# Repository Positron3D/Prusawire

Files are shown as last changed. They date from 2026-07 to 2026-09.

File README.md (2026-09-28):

# Prusawire 2026.R1

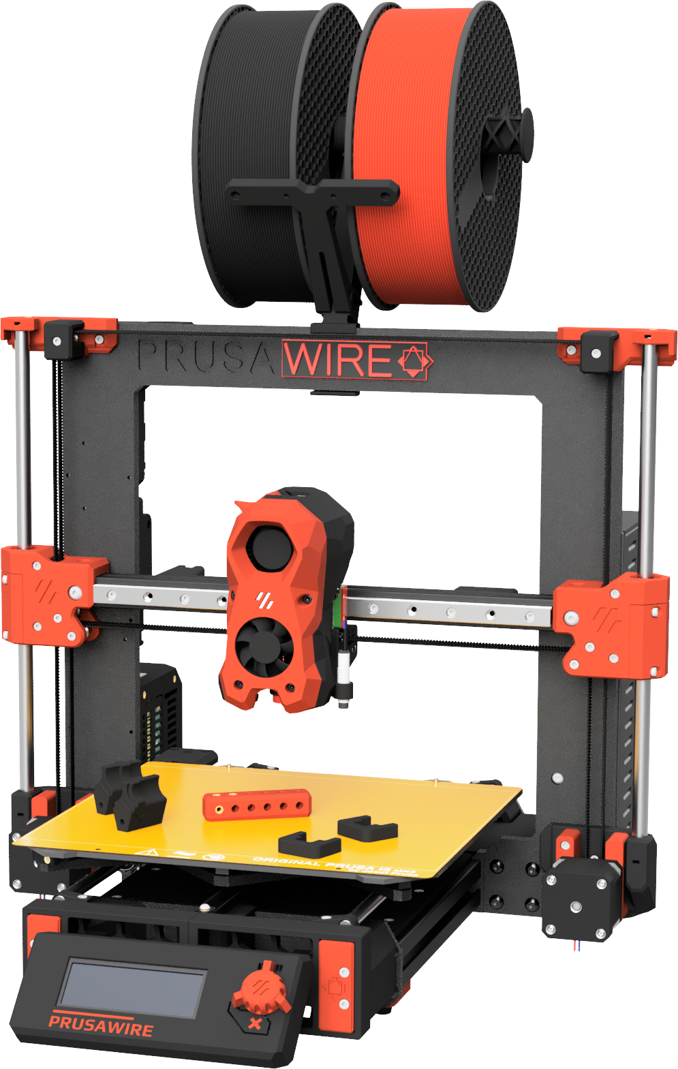
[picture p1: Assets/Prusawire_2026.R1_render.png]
Prusawire 2026.R1 Render


A Prusa MK3/MK4 to Voron Switchwire Conversion. Originally from Positron 3D's 2025 April Fools, transformed into a mature and fun 3D printer!

Build Volume: 250mm (X) by 210mm (Y) by 185mm (Z).

## Current Release

2026.R1 was released on 2026-07-24.

[Article: Prusawire R1 - Designed With Leftovers](https://www.printables.com/article/prusawire-r1-designed-with-leftovers-VNGb2GZ).

View the [changelog](CHANGELOG.md) for a for detailed listing of project evolution.

Be sure to grab the latest STLs and documentation from the GitHub Repository or use the _NEW_ [Prusawire Configurator](https://configurator.positron3d.com) to configure your Prusawire, visualize it, and download the STLs you need for your build!

## Upgrading from Beta 1
- Everything to do with XZ Axis has changed and is not compatible with R1.
- Everything to do with Y Axis has changed and is not compatible with R1.
- Electronics adjacent components (Mainboard, RPi Mount, Wago, Toolhead Board, etc), Door Idler components, Gantry Bumper, LCD Cover, and Front Panel/deck cover can be re-used.
- Existing belts can be re-used (although, depending how the belts were trimmed, it's possible you may need to replace them for being too short)

## Manual & Documentation

[Assembly Manual](Manuals/Prusawire_2026.R1_Assembly_Manual.pdf).

[Prusawire Documentation and FAQ Site](https://prusawire.positron3d.com).

The [Official Positron3D CAD Viewer](https://cad.positron3d.com?model=Prusawire_2026.R1) can be very helpful in building Prusawire.

Be sure to post your _Make_ on the [Prusawire Printables page](https://www.printables.com/model/1788294-prusawire-2026r1)!

## Bill of Materials

[Prusawire 2026.R1 Bill of Materials](https://docs.google.com/spreadsheets/d/16whAEq4oKpdtc77cCxrXZkcxw_G3URlF5wZYUE42vhc/)

Prusawire will require ~1060g of primary color filament and ~225g of accent color filament.  Accessory and component choices may affect these estimates slightly.

## Who This Printer is For

- You have an old MK3, MK3S, or MK3S+, and you want to teach an old dog new tricks and are on a budget
- You upgraded from MK4S to a Core ONE, and have a leftover frame. You are okay spending money on building a new printer with that hardware.
- You have a MK4 or MK4S that you want to Klipper-ize and experiment with!

Additionally, the following says this printer is for you: 

- You want to take your first steps into RepRap beyond Prusa, and Voron is an exciting route.
- You respect the Frankenstein-y nature of this April Fools joke printer

## Want to Support the Project?

First of all, thank you!

- Support Positron3D to fund future endeavors: 
   - [Donate to Positron3D](https://www.paypal.com/donate/?hosted_button_id=YGPRVTSHN4FQG)
   - [Positron3D Merch](https://nomadsgalaxy-shop.fourthwall.com/)

## Serial Numbers

We are accepting serial number requests on the [Positron 3D Discord](https://discord.gg/positron). Please submit your request to the #prusawire-serial-request channel over there. 

*Important Note:* Prusawire is _not_ a Voron Switchwire.  Please do not ask for help in the Voron Discord; instead utilize the #prusawire-discussions and #prusawire-questions channels on the Positron 3D Discord.

## Klipper Configuration Files

The most up–to–date Klipper configuration files for setting up or updating the Prusawire are in our [config repository](https://github.com/Positron3D/prusawire-klipper-config).

## Upgrading the Einsy Rambo to Klipper - Read this

Installing Klipper on the Einsy Rambo board is possible, with extra steps. Follow the guide [published by the awesome folks at MyRigs3D](https://myrigs3d.com/blogs/infos/revive-your-prusa-mk3s-with-klipper-1-5-flash-bootloader)! We recommend Method 2.

**Note:** Some users have reported problems using `avrdude` with the latest Raspberry Pi OS version (bookworm). If you experience error messages from avrdude complaining about gpio ports being busy, please try using the bullseye version of Raspberry Pi OS instead, available as "Raspberry Pi OS (Legacy)" in Raspberry Pi Imager.

## Credits 

Thank you to all the awesome people and companies that have made this possible.
- Positron 3D Team
- Nomads Galaxy, initial idea
- Ella Fox, the architect of Prusawire Beta 1
- Prusa Research - Prusa i3
- Voron Design - Switchwire
- Jason @ LDO Motors - Part sponsorship
- Levendigs & KB-3D - Part sponsorship
- Siraya Tech Filaments
- The many early access and beta testers

We hope you enjoy this build as much as we enjoyed making it.

The Prusawire Team:
@Safe // @erikbuild // @TheNexusAvenger

## Extra Credits for Existing Printed Parts

See the collection for the most up to date! To name them:

- Printable M3 T-Nuts for 3030 Extrusion, by Kapplion
- Stealthburner umbilical strain relief, by nagelwerkstatt

## Team

Prusawire is currently maintained by the Positron 3D Team.

- Design Lead: @Safe
- Documentation Lead: @erikbuild
- Software Lead: @TheNexusAvenger

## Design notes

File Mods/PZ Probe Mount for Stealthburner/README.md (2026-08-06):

A PZ Probe mount for the Prusawire. Use two M2 self-threading screws up to about 10mm in length to mount it. You may lose some Z distance with this mod as it may interfere with the belt path at the top.

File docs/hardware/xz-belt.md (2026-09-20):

---
layout: default
title: XZ Belt Installation and Tensioning
parent: Hardware Overview
nav_order: 2
---

# XZ Belt Installation and Tensioning
{: .no_toc}

<details open markdown="block">
  <summary>
    Table of contents
  </summary>
  {: .text-delta }
- TOC
{:toc}
</details>

**Compatibility:** *Prusawire 2026.R1*

## Overview
The X and Z belts must be installed and tensioned properly to ensure smooth and accurate gantry motion.

**Important notes:**
- Extra belt length has been specified in the BOM; it is expected to have some leftover belt afterwards.
- Match your belt lengths before assembling the printer!
- When inserting the belt clips, there should be an equal number of teeth sticking out of the ends.
- **DO NOT cut your belts** until you are 1000% certain you have done it correctly.  It's okay to leave a little extra length hanging out the back of the toolhead carriage until final assembly and validation.

## Prerequisites
- Complete the Gantry Deracking procedure.
- Remove the **toolhead** from the **carriage mount** (if currently installed).
	1. For Stealthburner, see the Stealthburner assembly manual for instructions.
- (Optional, but highly recommended) Print and assemble the GT2 Belt Runner to easily and perfectly match your belt lengths: [Belt Runner - GT2 Belt Length Matcher \| Printables.com](https://www.printables.com/model/1192440-belt-runner-gt2-belt-length-matcher)

## Instructions 
### Belt Installation
1. Measure out 1600mm of GT2 belt for the X axis.  Double-check your measurement, then cut this length.  Set aside for now.
	- *Tip: Mark some tape on your desk with 100mm increments using a tape measure or calipers.*

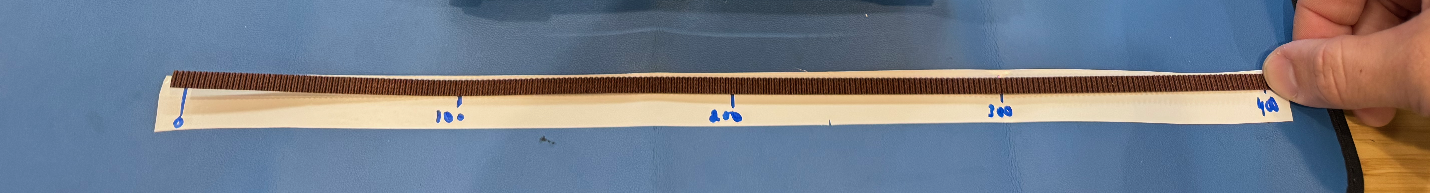
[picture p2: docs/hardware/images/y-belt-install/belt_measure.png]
	

2. Measure out another ~1600mm length of GT2 belt for the Z axis.  **Do not cut it yet!**
3. Match the belt lengths (*note: if not using the GT2 Belt Runner, carefully match the belt lengths by hand!*)
	1. Align the starting teeth of the of the X belt and Z belt.  
	2. Feed into the GT2 Belt Runner (see above).  
	3. Use belt runner to find the exact same length of Z belt as X belt.  Note one belt will be exactly one tooth offset from the other.  
	4. Once you are sure the belts are the same length, cut the **Z belt** to match the **X belt**.

	
	
4. Using tape or a zip tie, raise the gantry about 75% of the way towards the top of the frame.

	
	
5. Remove the 4x **M3x14 SHCS** securing the **x carriage assembly** to the linear rail.  Remove the assembly.
	
	

6. Remove the 3x **M3x40 SHCS** from the left side of the **x-carriage assembly** to separate the left side from the right side.
	
	

7. Gather all the needed parts:
	- 2x **1600mm Gates GT2 Belt**
	- 2x **M3x40 SHCS**
	- 2x **\[a]_belt_tensioner_clip**
	- 2x **\[a]_belt_clip**
	- 2x **belt_clip**
	- 4x **M3x14 SHCS**
	- 1x **x-carriage - left side**
	- 1x **x-carriage - right side**

	
    
8. Take the **x-carriage - right side** and install it back onto the **x-carriage mount** (on the rail) with 2x **M3x14 SHCS**.
9. Take the first **\[a]_belt_tensioner_clip**.  Feed a small amount of one of the belts (belt teeth facing up) through the slot on the side with the heat insert.  Pass just enough belt through so 3 teeth are visible from the opposite side.  Insert a **belt_clip** under to secure.
	- *Tip: You can press the retaining clip against a flat surface to help force the retaining clip into the tensioner clip.*
    
	
	

10. Repeat this process for the other clip and belt.  It is critical for both clips to have the same number of exposed belt teeth showing.
11. Pass the long end of each belt (teeth facing up) through the two slots from the inside to the outside of the mounted **x-carriage - right side**.
	- *NOTE: The **\[a]_belt_tensioner_clip** with the single dot goes towards the rear of the printer.  The clip with the two dots goes towards the front of the printer.

	
	

12. **Z Belt**: Route the belt through the belt path (see diagram; belt path noted in GREEN):
	1. Right towards the **XZ Block - Right**.
	2. Around the bearing stack and down towards the **Z Motor**.
	3. Back up around the **Z Motor Pulley** through the **XZ Block - Right** towards the **Idler Block - Right**.
	4. Around the bearing stack and left towards **Idler Block - Left**.
	5. Around the bearing stack and down towards **XZ Block - Left**.
	6. Around the bearing stack and right towards the **X-carriage**.
	7. *Tip: Make sure the belt isn't twisted at any point!*
	8. *Tip: Check the Z Motor Pulley alignment with the belt.  Adjust with the set screws on the pulley if needed to ensure good belt alignment that doesn't rub on the motor mounts.*

	
	

13. **X Belt**: Route the belt through the belt path (see diagram; belt path noted in YELLOW):
	1. Right towards the **XZ Block - Right**.
	2. Around the bearing stack and up towards **Idler Block - Right**.
	3. Around the bearing stack and left towards **Idler Block - Left**.
	4. Around the bearing stack and down through **XZ Block - Left** towards **X Motor**.
	5. Back up around the **X Motor Pulley** towards **XZ Block - Left**.
	6. Around the bearing block and right towards the **x-carriage**.
	7. *Tip: Make sure the belt isn't twisted at any point!*
	8. *Tip: Check the X Motor Pulley alignment with the belt.  Adjust with the set screws on the pulley if needed to ensure good belt alignment that doesn't rub on the motor mounts.*

	

14. Pass the two belts through the outside of the **x-carriage - left side**.  
	
	

15. Rejoin the **x-carriage - left side** to the mounted carriage with the 3x **M3x40 SHCS**.  Direct the excess belt length down for now.

	

16. Pull the excess belts evenly to remove the slack from the belt system.  Carefully line up the ends of the belts to ensure they are the same length and the ends match up evenly.
17. Insert both **\[a]_belt_clips** to secure the belts to the left side of the carriage.

	

18. Confirm once again the ends of the belts are perfectly aligned.  If they have shifted, remove the clips and re-adjust.
19. Unmount the **x-carriage assembly** from the linear rail one last time by removing the 2x **M3x14 SHCS** from the front.
20. Carefully rotate the assembly towards you to view the belts inside.

	

21. Leaving 3 to 4 teeth exposed on the left side of the assembly, carefully cut the belts.

	

22. Re-mount the assembly back onto the linear rail carriage with all 4x **M3x14 SHCS**.
23. Install the 2x **M3 x 40 SHCS** into the left side of the **x-carriage assembly** and screw into the **\[a]_belt_tensioner_clips** until just seated.
	
	

24. You are finished and ready to tension the XZ Belts!

	

### Belt Tensioning
To properly tension the X and Z belts:
1. Begin turning the two **M3x40 SHCS tensioning screws** in the **x-carriage assembly**.
	- Turn clockwise to increase tension.
	- Turn counterclockwise to decrease tension.
2. Once slack is removed, and prior to final tension:
	- **TRIPLE CHECK YOUR BELTS to make sure they are riding correctly on the bearings and pulleys.  If they aren't, loosen and correct.**
3. If the tensioning screw bottoms out you can either:
	- Replace the M3x40 SHCS with a fully threaded version
	- Try tensioning both belts a few more groove notches on the left side of the **x-carriage assembly** and re-installing the **\[a]_belt_tensioner_clips** to secure.

4. Visually inspect your X carriage belt tensioner. If your belts are not stretched, you should see that the two tensioner blocks are almost in line with one another. 
	
	
    
5. Come to the front of the printer and inspect the right side of your X carriage. Your belt teeth should align with one another. If they do not, make minor adjustments to the tensioner screws until they do.
	
	

6. Follow up with tuning your belt tension with one of the final tensioning options below.

**Final Tensioning Options:**
- **PF Makes Belt Tensioning Meter:** [3D-Printer/GT2 Belt Tension Meter at main · Diyshift/3D-Printer · GitHub](https://github.com/Diyshift/3D-Printer/tree/main/GT2%20Belt%20Tension%20Meter)
	- Switchwire "Z" Spec - 1.8 to 2.2 (1.9 to 2.3 for EPDM high-temp belt)
- **Prusa Mobile App:** 
	- [Prusa on the Apple App Store](https://apps.apple.com/us/app/prusa/id6477531937)
	- [Prusa - Apps on Google Play](https://play.google.com/store/apps/details?id=com.prusa3d.connect&hl=en-US&pli=1)
	- Tuner Mode for *MK3S --> X-Axis*
		- Carriage all the way to the right
- **Prusa Website Tuner:** [Prusa Belt tuner](https://belt.connect.prusa3d.com/)
	- *MK3S --> X-Axis*
		- Carriage all the way to the right
- **Gates Carbon Drive Mobile App**
	- [Carbon Drive Belt Tension Tool on the Apple App Store](https://apps.apple.com/app/bicycle-belt-tension-meter/id438346486)
	- [Carbon Drive - Apps on Google Play](https://play.google.com/store/apps/details?id=com.gates.carbondrivecalculator&hl=en)
	- 85 Hz

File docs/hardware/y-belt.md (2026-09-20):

---
layout: default
title: Y Belt Installation and Tensioning
parent: Hardware Overview
nav_order: 2
---

# Y Belt Installation and Tensioning
{: .no_toc}

<details open markdown="block">
  <summary>
    Table of contents
  </summary>
  {: .text-delta }
- TOC
{:toc}
</details>

**Compatibility:** *Prusawire 2026.R1*

## Overview
The Y belt must be installed and tensioned properly to ensure smooth and accurate bed motion.

**Important notes:**
- Extra belt length has been specified in the BOM; it is expected to have some leftover belt afterwards.
- Match your belt lengths before assembling the printer!
- When inserting the belt clips, there should be an equal number of teeth sticking out of the ends.
- **DO NOT cut your belts** until you are 1000% certain you have done it correctly.  It's okay to leave a little extra length hanging out the back of the toolhead carriage until final assembly and validation.

## Prerequisites
- You will likely find this easiest without the MK52 Heat Bed installed!

## Instructions 
### Belt Installation
1. Measure out 1000mm of GT2 belt for the Y axis.  Double-check your measurement, then cut this length.  Set aside for now.
	- *Tip: Mark some tape on your desk with 100mm increments using a tape measure or calipers.*

	

2. Gather all the needed parts:
	- 1x **1000mm Gates GT2 Belt**

3. Slightly loosen the M3x10 BHCS securing **y_belt_tensioner** to the Y Carriage.  Loosen the M3x20 SHCS tensioning screw almost all the way so the **y_belt_tensioner_front** can be pulled apart as much as possible (while the M3x20 is still engaged with the square nut).  This is the position of LEAST belt tension.

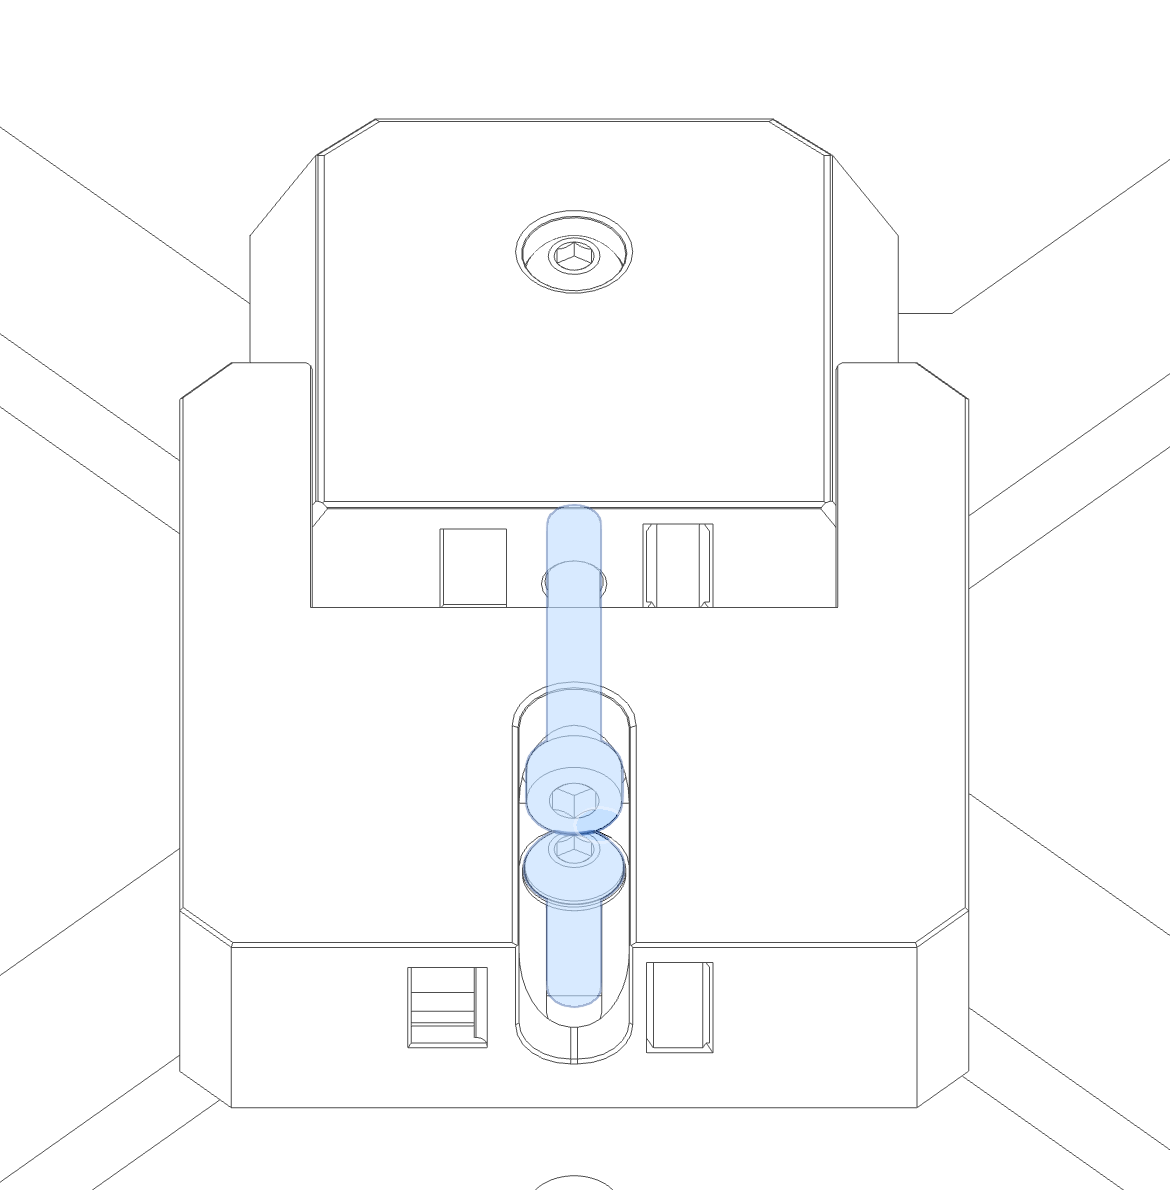
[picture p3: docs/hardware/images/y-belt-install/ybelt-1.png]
	
 
4. Insert one end of the belt into **y_belt_tensioner** as shown.  Ensure at least 6 teeth of the belt are in contact with the ridges on the tensioner.

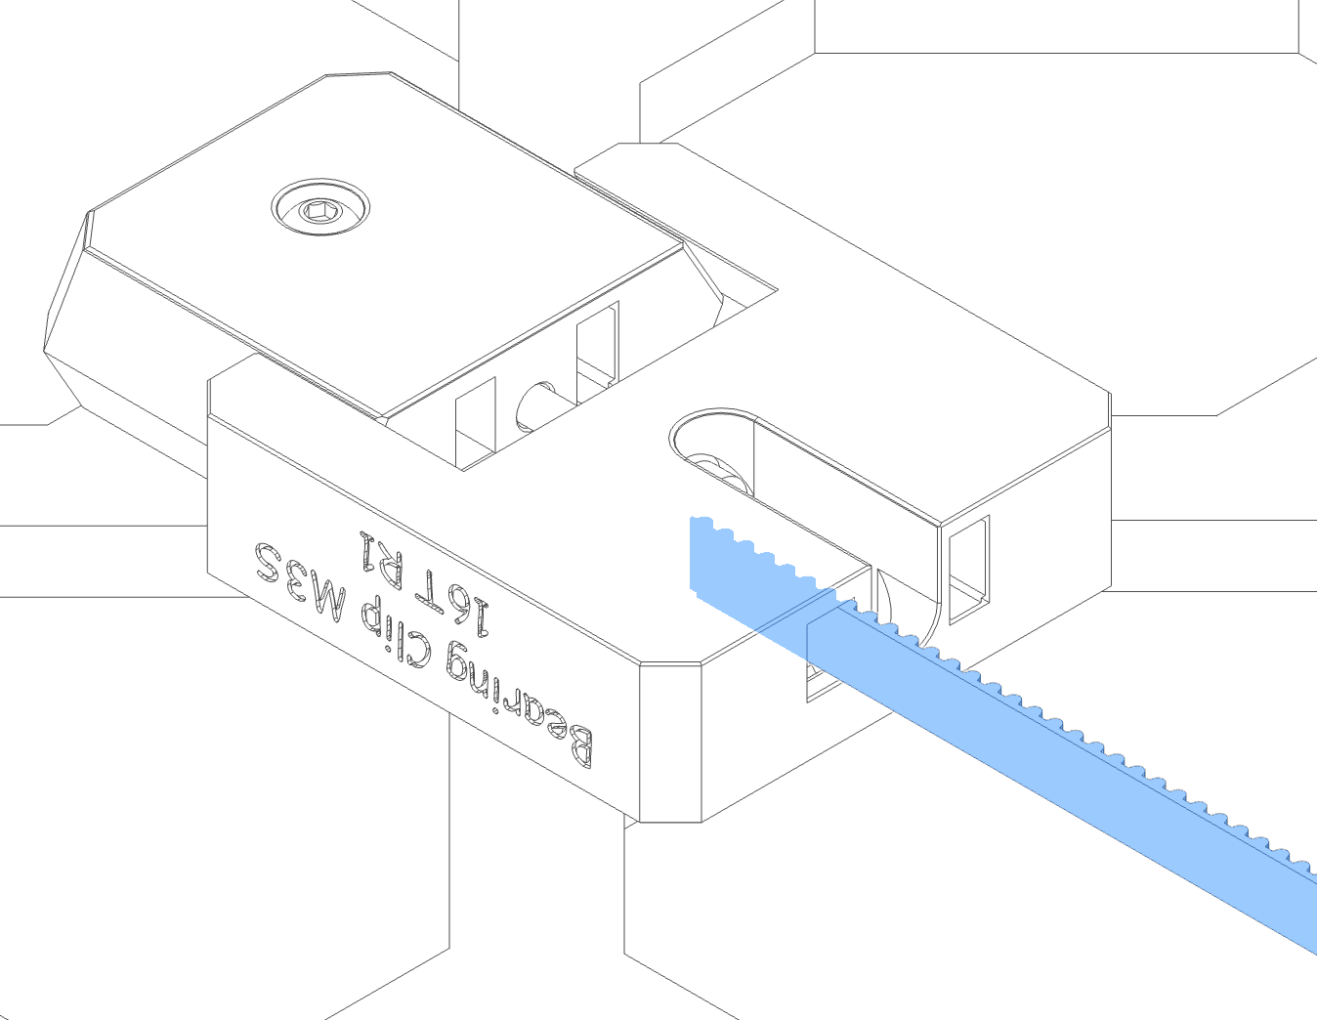
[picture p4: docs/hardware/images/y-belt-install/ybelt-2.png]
	

5. Insert **[a]_belt_clip** to secure the belt.

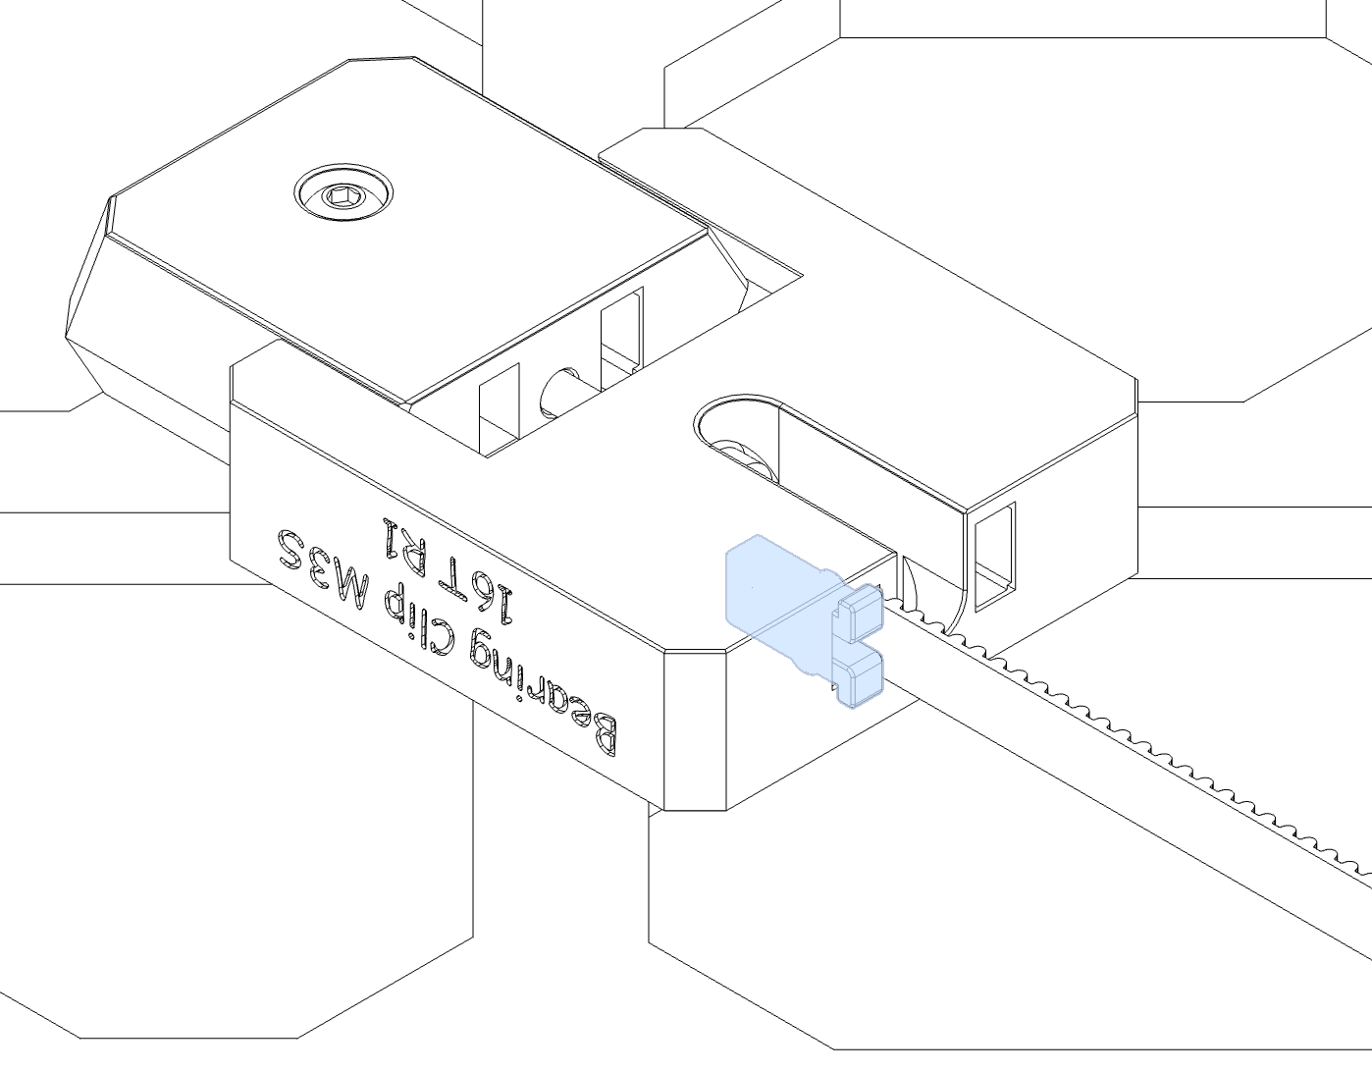
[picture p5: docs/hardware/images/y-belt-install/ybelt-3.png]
	

6. Route the belt towards the front, around the front idler bearing stack, back into and through both halves of **y_belt_tensioner** towards the back of the printer.

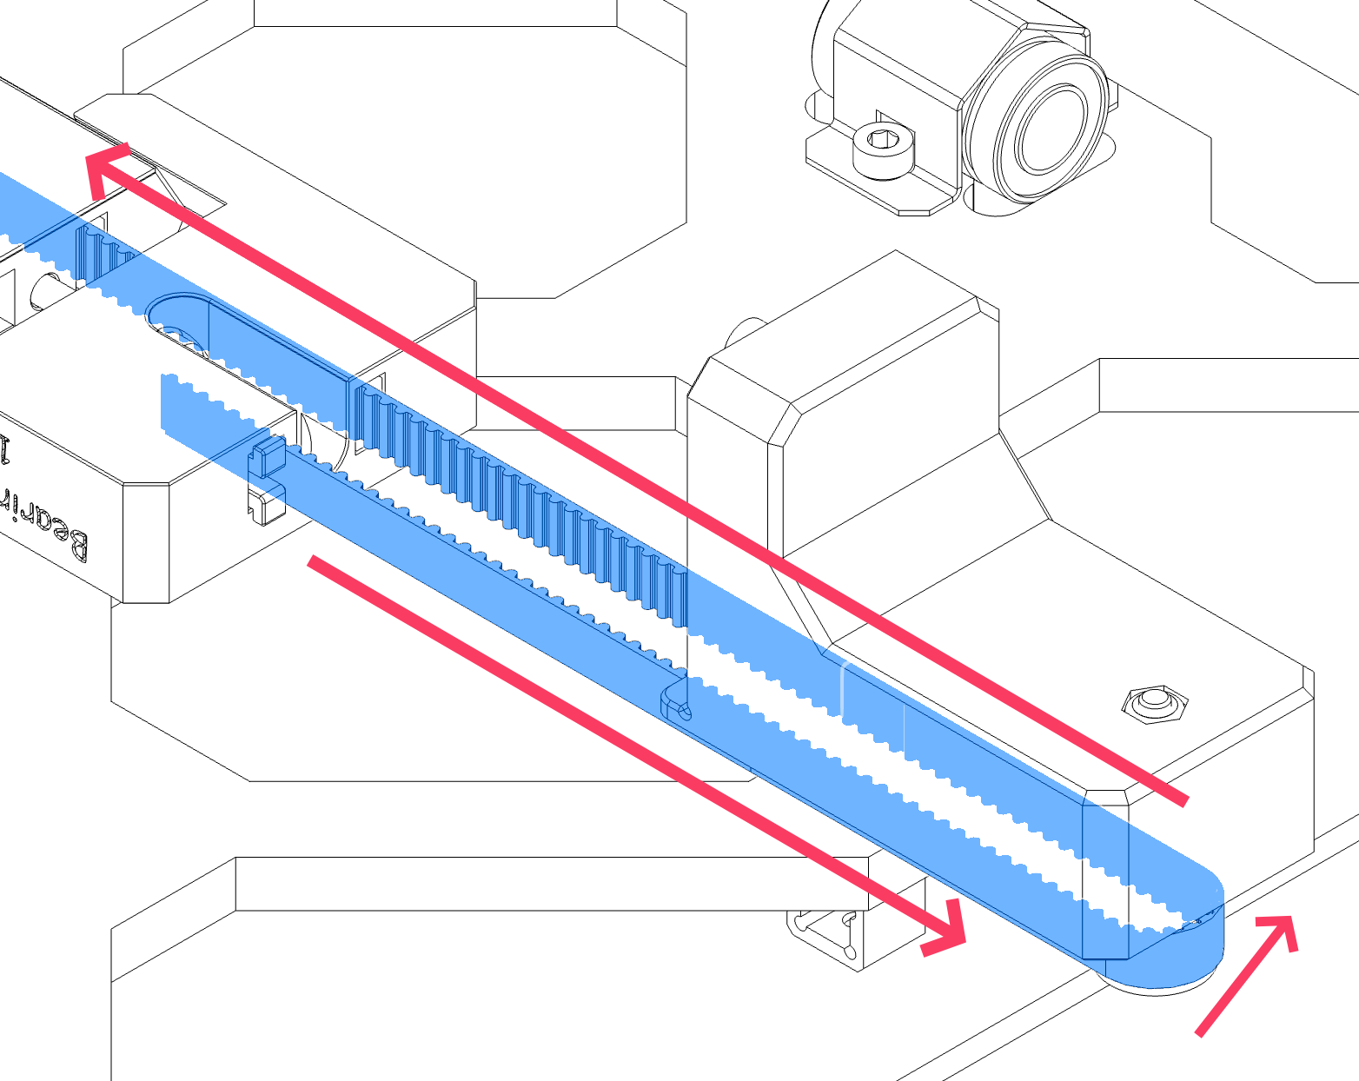
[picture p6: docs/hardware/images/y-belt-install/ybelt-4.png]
	
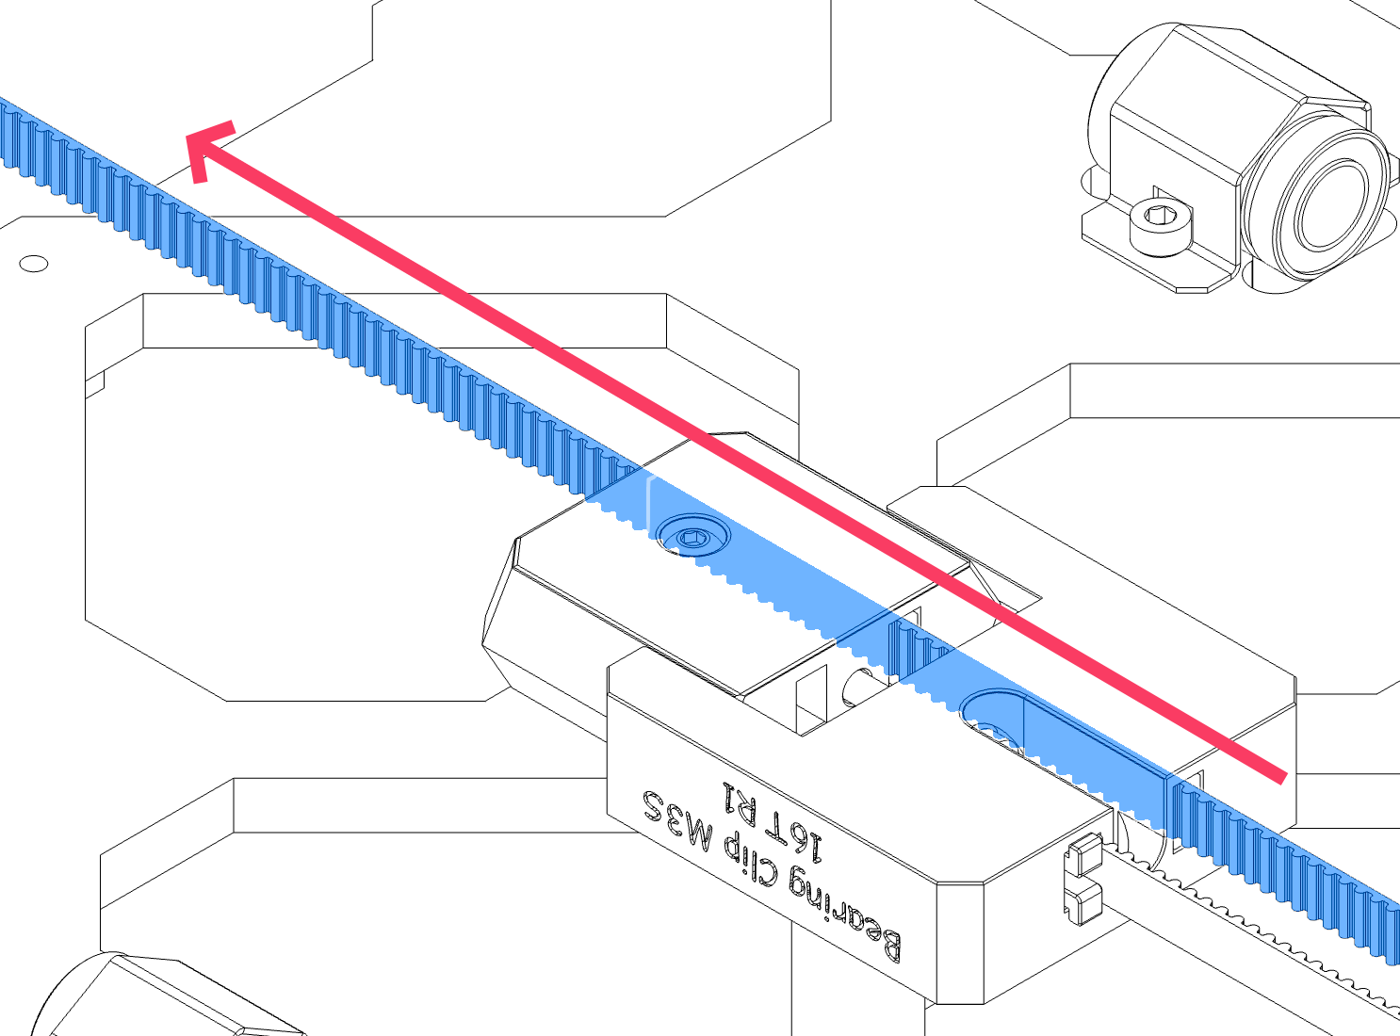
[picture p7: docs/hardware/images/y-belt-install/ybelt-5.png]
	

7. Route the belt around the Y Motor Pulley and back around towards the front of the printer as shown.

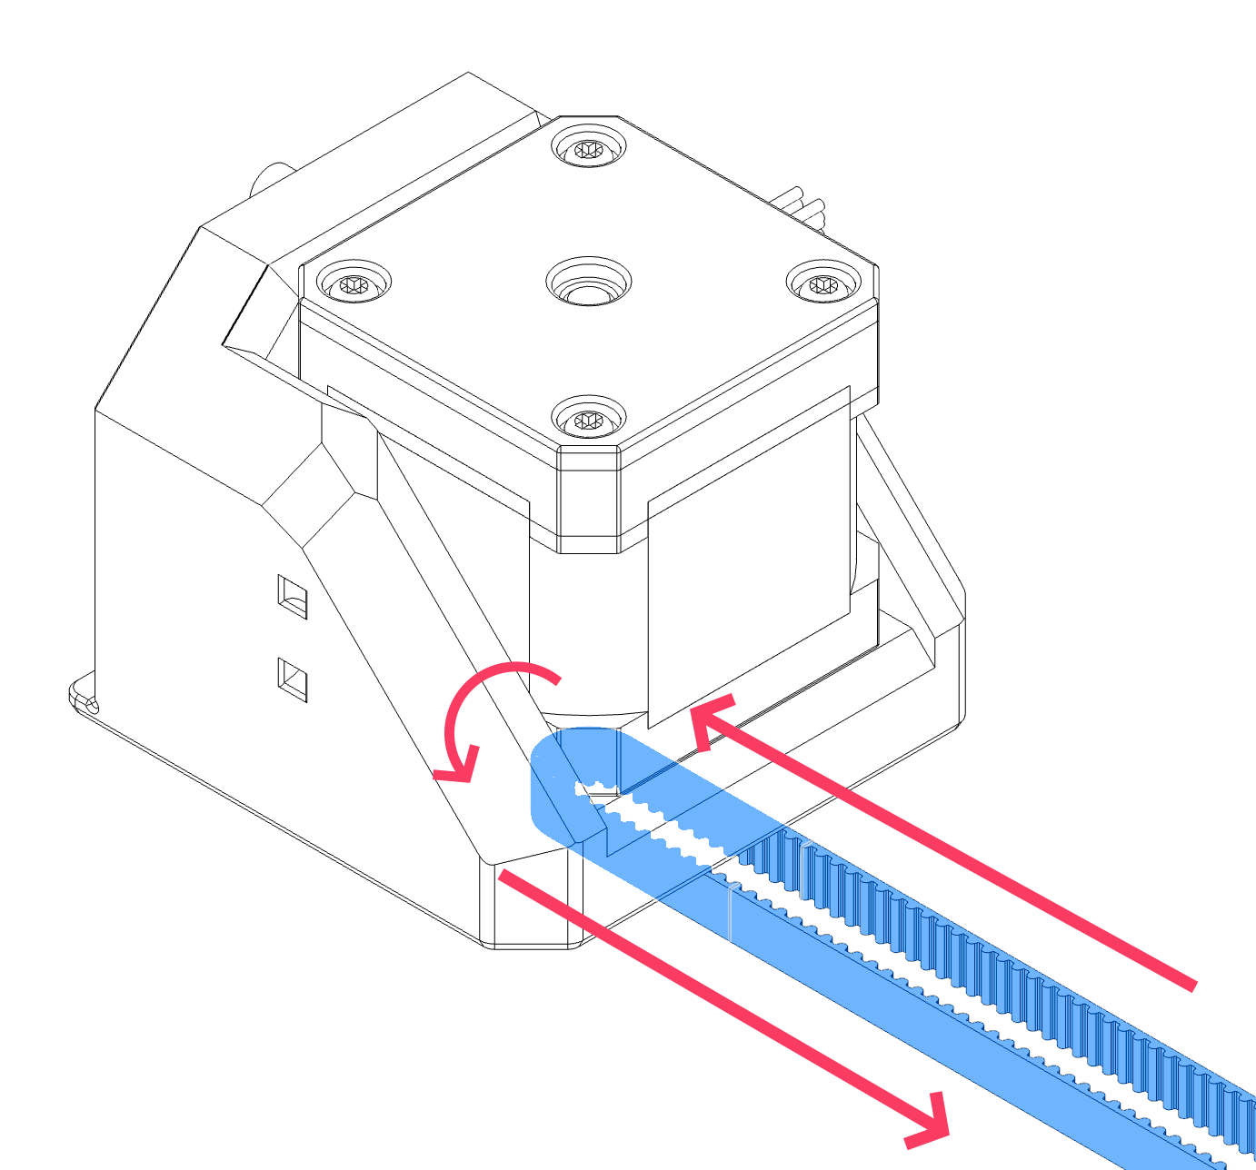
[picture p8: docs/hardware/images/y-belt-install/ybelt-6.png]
	

8. Route the belt around the Y Motor Pulley and back around towards the front of the printer as shown.

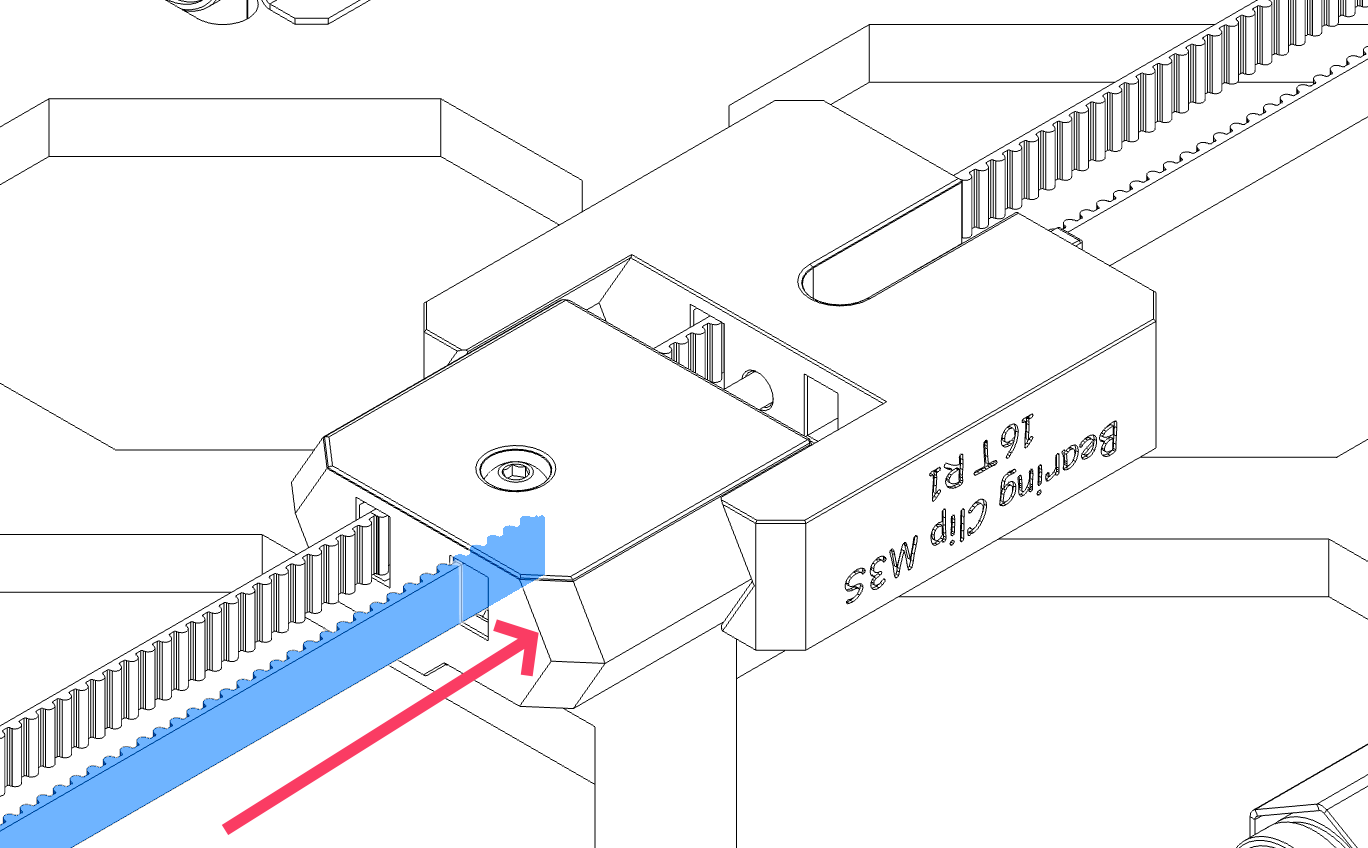
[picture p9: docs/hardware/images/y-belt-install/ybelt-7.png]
	

9. Insert the other end of the belt into the belt slot on the back of the **y_belt_tensioner**.  You will need to trim the belt carefully at this point.  You want to have minimal to no slack in the belt and still have at least 5-6 teeth inside and engaged with the belt tensioner.  Secure with a belt clip.  *This may take a few tries to get perfect.  Err on the side of too long, you can always remove the belt clip and trim a little more off if you find it has too much slack!*.

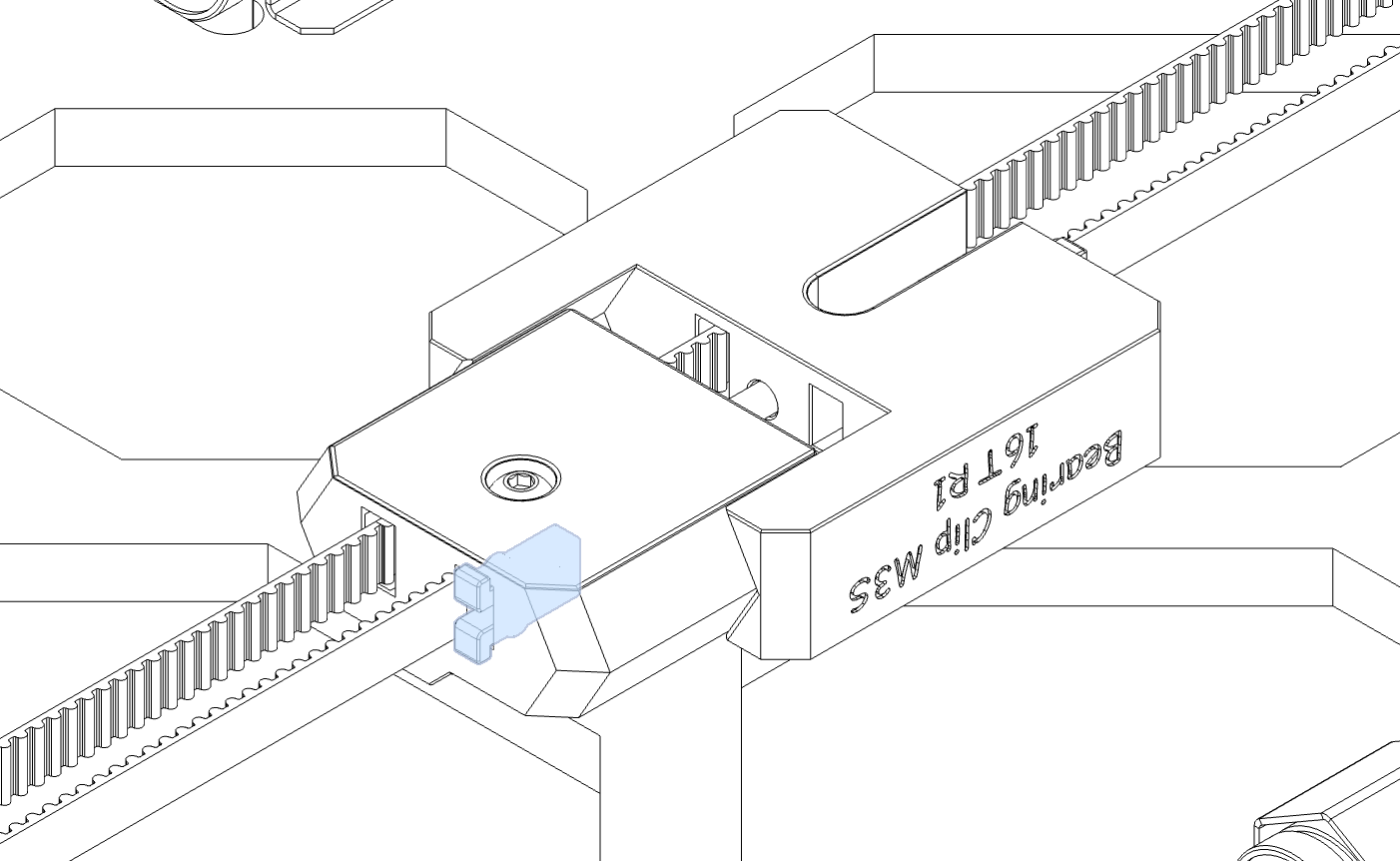
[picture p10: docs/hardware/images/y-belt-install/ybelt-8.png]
	

### Belt Tensioning
To properly tension the Y belts:

1. Begin turning the **M3x20 SHCS tensioning screw** in the **y_belt_tensioner**.
	- Turn clockwise to increase tension.
	- Turn counterclockwise to decrease tension.



2. Once slack is removed, and prior to final tension:
	- **TRIPLE CHECK YOUR BELT to make sure it is riding correctly on the bearings and pulleys.  If it is not, loosen and correct.**

3. If the tensioning screw bottoms out (and you do not have adequate tension in the belts)
	- Loosen the tensioning bolt, try inserting one or both ends of the y belt a few more groove notches into the **y_belt_tensioner** and re-installing the belt clips to secure.  Tighten the tensioning screw again.

4. Follow up with tuning your belt tension with one of the final tensioning options below.  **Once you are satisfied, secure the assembly by tightening the M3x10 BHCS securing the tensioner to the Y Carriage!**

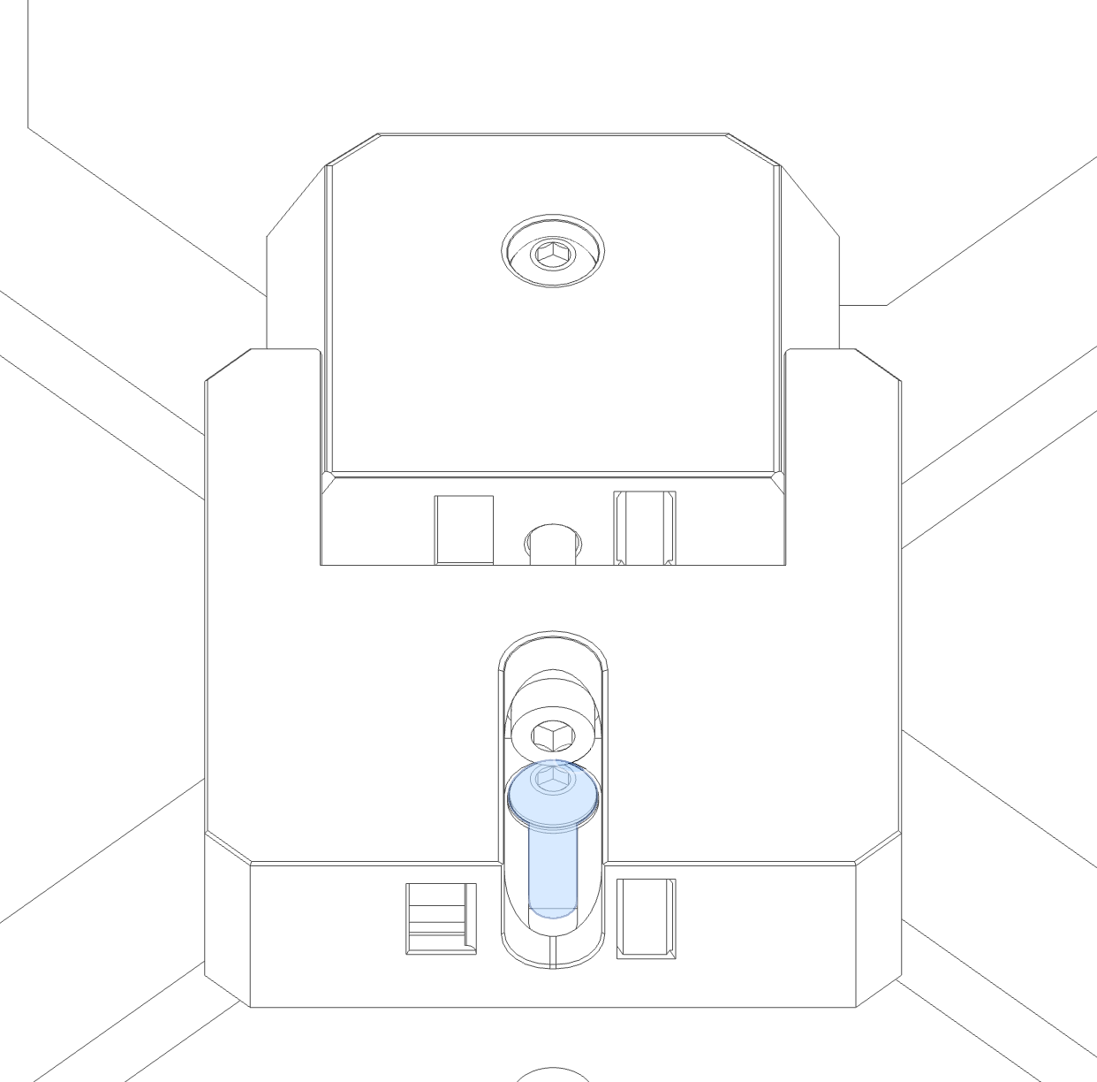
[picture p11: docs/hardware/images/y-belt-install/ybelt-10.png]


**Final Tensioning Options:**
- **PF Makes Belt Tensioning Meter:** [3D-Printer/GT2 Belt Tension Meter at main · Diyshift/3D-Printer · GitHub](https://github.com/Diyshift/3D-Printer/tree/main/GT2%20Belt%20Tension%20Meter)
	- Switchwire "Z" Spec - 1.8 to 2.2 (1.9 to 2.3 for EPDM high-temp belt)
- **Prusa Mobile App:** 
	- [Prusa on the Apple App Store](https://apps.apple.com/us/app/prusa/id6477531937)
	- [Prusa - Apps on Google Play](https://play.google.com/store/apps/details?id=com.prusa3d.connect&hl=en-US&pli=1)
	- Tuner Mode for *MK3S --> Y-Axis*
		- Carriage all the way to the right
- **Prusa Website Tuner:** [Prusa Belt tuner](https://belt.connect.prusa3d.com/)
	- *MK3S --> Y-Axis*
		- Carriage all the way to the right
- **Gates Carbon Drive Mobile App**
	- [Carbon Drive Belt Tension Tool on the Apple App Store](https://apps.apple.com/app/bicycle-belt-tension-meter/id438346486)
	- [Carbon Drive - Apps on Google Play](https://play.google.com/store/apps/details?id=com.gates.carbondrivecalculator&hl=en)
	- 85 Hz

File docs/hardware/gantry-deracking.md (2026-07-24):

---
layout: default
title: Gantry Deracking
parent: Hardware Overview
nav_order: 1
---

# Gantry Deracking
{: .no_toc}

<details open markdown="block">
  <summary>
    Table of contents
  </summary>
  {: .text-delta }
- TOC
{:toc}
</details>

**Compatibility:** *Prusawire 2026.R1*

## Overview
The gantry de-racking procedure is critical to ensure smooth motion in X and Z.  The general idea is to loosen certain screws on the gantry, bump the bottom of the gantry against the X and Z motor joints to align, and tighten the screws.

## Prerequisites
- Confirm your frame geometry is square: [Frame Assembly - Geometry Check](https://help.prusa3d.com/guide/2-frame-assembly_427481#427929)
- The following should be assembled already:
	- Frame
	- Z-Axis
	- X-Gantry with toolhead mount
- You should be ready to belt both the X and Z axis.

## Instructions
1. Remove the **toolhead** from the **carriage mount** (if currently installed).
	1. For Stealthburner, see the Stealthburner assembly manual for instructions.
2. Remove the **bed**, **y-carriage**, and **y-rods** completely off the printer (if currently installed).
3. Remove the **bumper block** and **door puller block** from the back of the gantry (if currently installed).

	

4. Remove the **top left idler assembly** and **top right idler assembly** loosening the M3 SHCS on each.  
	1. *TIP: A small piece of tape on the top and bottom of the assembly can be used to help keep the bearing stack together.*

	
	

5. Remove the **x-gantry assembly from the printer** by lifting it up off the z-axis rods.
6. Loosen all six **M5 BHCS** from each side of the x-gantry assembly.

	

7. Ensure each end of the 2020 extrusion is seated ALL the way into the printed parts.
8. Re-install the **x-gantry assembly** onto the printer by sliding it onto the z-axis rods from the top.
9. Move the **x-gantry assembly** up and down a few times to allow parts to settle.
10. Lower the **x-gantry assembly** until it bumps against the X and Z motor mounts.

	

11. Tighten the two top M5 BHCS on the x-gantry assembly, followed by the two front M5 BHCS.

	

12. Raise the **x-gantry assembly** up to the top just high enough to be able to tighten the rear two M5 BHCS.

	

13. Lower the **x-gantry assembly** back down to the bottom.
14. Re-install the **top left idler assembly** and **top right idler assembly** by tightening the two M3 SHCS on each.
15. Re-install the **bumper block** and **door puller block** on the rear of the gantry.
16. Move the gantry up and down.  You shouldn't feel any resistance.

	

	1. When the gantry bumps the top of the frame, it should bump equally on both sides.

	

	2. When the gantry bumps the bottom (X motor mount and Z motor mount), it should bump equally on both sides.

	

17. Check for any gantry racking a final time after installing XZ belts (and prior to installation of Y-axis).  Adjust front/top M5 screws if needed.

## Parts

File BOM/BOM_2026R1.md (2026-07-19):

# Prusawire 2026.R1 Bill of Materials

Current / Up to date BOM and Sourcing Guide:

[Prusawire 2026.R1 Bill of Materials](https://docs.google.com/spreadsheets/d/16whAEq4oKpdtc77cCxrXZkcxw_G3URlF5wZYUE42vhc/)

Note: The XLSX saved in this folder may not be the most current; we suggest using the Google Sheets link above for the latest!

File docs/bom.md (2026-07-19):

---
layout: default
title: "Bill of Materials"
nav_order: 4
---

# Bill of Materials (BOM)

[Prusawire 2026.R1 Bill of Materials](https://docs.google.com/spreadsheets/d/16whAEq4oKpdtc77cCxrXZkcxw_G3URlF5wZYUE42vhc/)

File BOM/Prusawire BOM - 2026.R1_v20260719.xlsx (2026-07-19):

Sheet: START HERE
PRUSAWIRE 2026.R1 BOM
Updated 2026-07-19
If you are starting with a...

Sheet: 2026R1 BOM - Complete
PRUSAWIRE 2026.R1 BOM - COMPLETE
Updated 2026-04-20
FILAMENT
ASA / ABS are recommended. ASA-GF and PC-CF can work as well. Many users have had success with glass filled materials, but note those can add stiffness.
Category | YOU CHOOSE! | Part | Quantity | Optional? | Notes | Source 1 | Source 2 | Source 3 | Source 4
Filament |  | Primary Color | 1.2kg |  | ASA / ABS preferred. ASA-GF works well. PC-CF is probably fine too
Filament |  | Secondary Color | 1kg |  | ASA / ABS preferred. ASA-GF works well. PC-CF is probably fine too
FASTENERS
The Prusawire Team is working with partners on hardware kits! In the interim, for fasteners, you can check out KB-3D / West3D / Bolt Depot / 3DKatten / TME (EU) / McMaster-Carr as possible sources.
*** KIT MAKERS: ADD 10%(ish) TO FASTENER COUNTS ***
Category | YOU CHOOSE! | Part | Quantity | Optional? | Notes | Source 1 | Source 2 | Source 3 | Source 4
Fasteners |  | M2x10 STS | 7 |  | Self-Tapping Screw for Plastics | https://kb-3d.com/store/inserts-fasteners-adhesives/275-m2x10mm-self-tapping-screw-for-plastic-hex-drive-1640931303062.html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 | https://west3d.com/products/self-tapping-screws-m2x10-self-tapping-screws?dt_id=524416
Fasteners |  | M3 Hex Nut | 45
Fasteners |  | M3 Nylon Lock Nut | 11
Fasteners |  | M3 Roll-In T Nut for 2020 Extrusion | 11
Fasteners |  | M3 Shims (3mm x 6mm x 0.5mm thick) | 34 |  | Absolutely do not use normal washers. These must be shim washers built to higher tolerances.
Fasteners |  | M3 Square Nut DIN 562 (Prusa Spec) | 19 |  | You may also use Voron V0 1515 Slim Style Square Nuts
Fasteners |  | M3 Threaded Insert (Voron Spec) | 68 |  | A few extra are included in the count, just in case.
Fasteners |  | M3x10 BHCS | 5
Fasteners |  | M3x16 BHCS | 2
Fasteners |  | M3x10 SHCS | 6
Fasteners |  | M3x12 FHCS | 15
Fasteners |  | M3x12 SHCS | 20
Fasteners |  | M3x14 SHCS | 5
Fasteners |  | M3x16 SHCS | 6
Fasteners |  | M3x20 SHCS | 16
Fasteners |  | M3x25 SHCS | 5 |  | Count does not include SB Fasteners
Fasteners |  | M3x30 BHCS | 2 |  | Used for the Y-axis front idler bearing stack.
Fasteners |  | M3x30 SHCS | 25 |  | Extra included in number for possible nozzle brush
Fasteners |  | M3x35 SHCS | 3
Fasteners |  | M3x40 SHCS | 7
Fasteners |  | M3x8 BHCS | 4
Fasteners |  | M3x8 SHCS | 15
Fasteners |  | M4x10 BHCS | 3
Fasteners |  | M5 Hex Nut | 3
Fasteners |  | M5 Roll-In T Nut for 2020 Extrusion | 7
Fasteners |  | M5x30 BHCS | 3
Fasteners |  | M5x8 BHCS | 7
ELECTRONICS
There is a third option for the power supply: a user mod exists for the common Meanwell LRS-350-24 (RSP-320-24 if you're in the EU), but it does require a few extra items not included in this BOM!
RECOMMENDED CHOICES:
Mainboard: BTT SKR Mini E3 V3.0
Power Supply: Prusa Black PSU
Toolhead Board: LDO NiteHawk-SB
Category | YOU CHOOSE! | Part | Quantity | Optional? | Notes | Source 1 | Source 2 | Source 3 | Source 4
Electronics |  | LDO Input Shaper Kit | 1 | yes | Highly recommend the LDO Input Shaper Kit for Y-Axis Input Shaper Tuning! | https://kb-3d.com/store/ldo/655-ldo-motors-input-shaper-kit-1661370490021.html?affp=22155 | https://west3d.com/products/ldo-input-shaper-toolkit?dt_id=524416
Electronics |  | Heatbed MK52 + Wires/Ring Terminals + Thermistor | 1 |  | If you're starting with a MK3 or MK4, you may already have a MK52 bed + thermistor + power cables. If you're coming from a CoreOne upgrade, you will need another one. Prusa is the "official" option, but Voron Switchwire beds or TriangleLab clones are valid options. Some of these come with wires and thermistors included. The Prusa option includes the Nylon support and textile sleeve as well! | https://www.prusa3d.com/product/heatbed-mk52-24v-xbuddy-replacement-set/ | https://west3d.com/products/prusa-mk3-heated-bed-trianglelab?dt_id=524416 | https://kb-3d.com/store/heated-bed-electronics/812-ldo-motors-heated-bed-for-switchwire-prusa-mk3-magnetic-24v-1677363868661.html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
Electronics | OPTION A | Daygreen 24VDC to 5VDC Converter (Buck) | 1 |  | Used to power Raspberry Pi and 5VDC Accessories | https://kb-3d.com/store/power-supplies-converters/259-dc-dc-converter-1224-volt-to-5v-10-amp-50-watt-1648320892173.html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 | https://west3d.com/products/dc-dc-24v-to-5v-buck-converter?dt_id=524416
Electronics | OPTION A | Raspberry Pi 4 Model B+ | 1 |  | You can also use a Pi 3 or BTT Klipper Pi, though it will be slower. Many users have had success with the Pi 5 as well. You can also use a Pi Zero 2 W if you're using the Einsey RAMbo for the mainboard!
Electronics | OPTION B | BTT PI 2 | 1 | yes | If you are looking at Raspberry Pi prices and want to look at an alternative, the BTT PI may be right for you. Note that you do not need to purchase the Buck Converter for this option.
Electronics |  | Hookup Wire - 15AWG (1.5mm) - Stranded - Black | 6 ft |  | For 24VDC wiring; 14/16awg is totally fine
Electronics |  | Hookup Wire - 15AWG (1.5mm) - Stranded - Red | 6 ft |  | For 24VDC wiring; 14/16awg is totally fine
Electronics |  | WAGO 221-413 | 4 |  | (3 position); For 24VDC and 5VDC wire connections. | https://kb-3d.com/store/wiring-connectors/925-8247-wago-lever-nut-wire-splice-connectors-multiple-sizes.html | https://west3d.com/products/wago-lever-nuts-fast-wire-cable-connectors-12-24awg-221-412-221-413-221-415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
Electronics |  | Misc assorted connectors (JST, Spade/Fork / Ring Terminals, etc) |  |  | Varies, depends on your choice of components
Mainboard | OPTION A | Einsy RAMbo + Prusa MK3 LCD Control | 1 |  | ONLY use this if you have one on hand. If you need to buy a board, the SKR is much better. The RAMbo is supported and a great way to re-use old MK3 era parts though!
Mainboard | OPTION B | BTT SKR Mini E3 V3.0 | 1 |  | If you need to buy a mainboard, this is our recommendation. There are a variety of user-tested mods for the BTT HDMI 5, BTT TFT5 screens, and more. | https://kb-3d.com/store/controllers-displays-drivers/420-bigtreetech-skr-mini-e3-v30-32-bit-control-board-1639888431041.html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 | https://west3d.com/products/btt-skr-mini-e3-v3-controller-board-3d-printer-control-system?dt_id=524416
Power Supply | OPTION A | Prusa Black PSU | 1 |  | This is recommended for new builds! If you are upcycling an old Prusa with the silver PSU, you can continue to use it. | https://www.prusa3d.com/product/psu-24v-240w-assembly/ | https://www.printedsolid.com/products/original-prusa-psu-24v-240w-assembly
Power Supply | OPTION B | Prusa Silver PSU | 1 | yes | Second hand only; ONLY if you have one lying around.
Power Supply | OPTION C | Meanwell LRS 350-24 | 1 | yes | Great for USA users, do not use in EU (use RSP-320-24 instead). | https://kb-3d.com/store/power-supplies-converters/185-meanwell-lrs-350-24-power-supply-24v-350w.html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 | https://west3d.com/products/mean-well-lrs-350-24-150w-24v-6-5a-power-supply-psu?dt_id=524416 | https://www.digikey.com/en/products/detail/mean-well-usa-inc/LRS-350-24/7705034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
Toolhead Board | OPTION A | LDO NiteHawk-SB | 1 | yes | We suggest using a Toolhead Board for ease of wiring and setup. If you're using the stock Stealthburner Toolhead, the LDO NiteHawk-SB (now in v2.0) is recommended. BTT SB2209 is also an option. | https://kb-3d.com/store/voron/1070-ldo-nitehawk-sb-usb-tool-head-for-voron-1706655144630.html?affp=22155 | https://west3d.com/products/nitehawk-stealthburner-toolboard-sb-pcb-by-ldo-motors?dt_id=524416
Toolhead Board | OPTION B | BTT EBB SB2209 USB | 1 | yes | We suggest using a Toolhead Board for ease of wiring and setup. If you're using the stock Stealthburner Toolhead, the LDO NiteHawk-SB (now in v2.0) is recommended. BTT SB2209 is also an option. | kb-3d.com/store/controllers-displays-drivers/916-bigtreetech-ebb-sb2209-can-usb-expansion-board-v10-for-voron-stealthburner-1687145055721.html?affp=22155
MOTION
There are a few choices here, and what you are starting from will drive them. If you are coming from a MK3, you will have all of the motors and pulleys you need. For the Z Rods, the 10mm Z Rods (MK4 spec) are a worthwhile upgrade.
RECOMMENDED CHOICES (for from scratch build):
Motor Pulleys: Option A - 20T
Motors: Option A - LDO Switchwire Motors
Z Rods: 10mm
Category | YOU CHOOSE! | Part | Quantity | Optional? | Notes | Source 1 | Source 2 | Source 3 | Source 4
Motion |  | F623-2RS Bearing | 20 |  | Don't cheap out here; use good quality bearings for smooth performance. | https://kb-3d.com/store/magnets-bearings/168-3x10x4-flanged-metric-ball-bearing-f623-2rs-6440891415288.html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 | https://west3d.com/products/f623-2rs-flange-ball-bearing?dt_id=524416
Motion |  | Gates GT2 Open Belt LL-2GT-6 (6mm) - 1000mm length | 1 |  | Y Axis | https://kb-3d.com/store/motion/215-gates-powergrip-2gt-belt-open-6mm-width.html?affp=22155 | https://west3d.com/products/gates-gt2-open-belt-ll-2gt-6-6mm-wide-voron-v0-v1-v2-switchwire?dt_id=524416 | https://3dkatten.se/products/gates-power-grip-gt-ll-2gt-epdm-balte-1-meter?variant=48182522741059
Motion |  | Gates GT2 Open Belt LL-2GT-6 (6mm) - 1600mm length | 2 |  | X and Z Axis | https://kb-3d.com/store/motion/215-gates-powergrip-2gt-belt-open-6mm-width.html?affp=22155 | https://west3d.com/products/gates-gt2-open-belt-ll-2gt-6-6mm-wide-voron-v0-v1-v2-switchwire?dt_id=524416 | https://3dkatten.se/products/gates-power-grip-gt-ll-2gt-epdm-balte-1-meter?variant=48182522741059
Motion |  | Linear Rod - 8x370mm | 2 |  | If starting from MK3/MK4, re-use X Axis Rods for this! We use these for Y-Axis on Prusawire. | https://www.prusa3d.com/product/smooth-rod-x-axis-mk4-mk3-s-mk2-5-s-mk2-s/
Motion |  | LM8UU | 3 |  | 3x for Y Carriage | https://www.prusa3d.com/product/linear-bearing-lm8uu/ | https://west3d.com/products/lm8uu-smooth-rod-8x15x45-linear-bearing?dt_id=524416 | https://levendigs.com/products/myt-lm8uu-linear-bearing-1pc | https://3do.dk/en/bearings/385-lm8uu.html
Motion |  | MGN12 Rail - 300mm with MGN12H Carriage, Z1 preload | 1 |  | Don't cheap out here; use a good quality rail for smooth performance. | https://kb-3d.com/store/motion/377-5160-kb3d-mgn12h-linear-rail-guide-with-carriage-multiple-lengths-1646161437836.html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 | https://west3d.com/products/west3d-printing-mgn12h-1r-300-350-400-linear-rails-with-carriages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 | https://3do.dk/en/linear-rails/1169-1567-ldo-stainless-mgn12h-rail-z1-preload.html#/96-length-300mm | https://hobby-store.pl/en/linear-rails/mgn12-linear-rail-400mm-with-mgn12h-carriage.html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
Motor Pulleys | OPTION A | GT2 20T 6mm Pulley (5mm bore) with Grub Screws | 3 |  | Voron Switchwire Spec (Recommended) | https://kb-3d.com/store/motion/213-gates-powergrip-2gt-pulley-20-tooth-5mm-6mm-1634481851944.html?affp=22155 | https://west3d.com/products/black-pulleys-and-idlers-gt2-20t-gt2-16t?variant=42151451525332&dt_id=524416
Motor Pulleys | OPTION B | GT2 16T 6mm Pulley (5mm bore) with Grub Screws | 3 |  | These are Prusa Spec; you will generally only be using these if re-using Prusa stepper motors | https://www.prusa3d.com/product/timing-pulley-t16-2gt/ | https://kb-3d.com/store/motion/214-gates-powergrip-2gt-pulley-16-tooth-5mm-6mm-1634481998632.html?affp=22155 | https://west3d.com/products/pulleys-and-idlers-gt2-20t-gt2-16t?variant=41970925830356&dt_id=524416
Motors | OPTION A | LDO 42STH40-1684AC Stepper Motor | 3 |  | Frequently found in Voron Switchwire motor kits; Also sometimes comes with pancake stepper for Stealthburner. This is a great option if you are building from leftovers after a Core One Upgrade kit. | https://kb-3d.com/store/electronics/436-ldo-voron-switchwire-stepper-motor-kit-4-piece-rev-c-1640807333865.html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 | https://west3d.com/products/ldo-motors-ldo-42sth40-1684ac-nema17-motor?dt_id=524416 | https://www.onetwo3d.co.uk/product/voron-switchwire-stepper-motor-kit-by-ldo/ | https://www.blurolls3d.com/products/blurolls-voron-switchwire-3d-printer-motors-kit-made-by-ldo-stepper-motor-kit-3pcs-ldo-42sth40-1684ac-1pc-ldo-36sth20-1004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
Motors | OPTION B | Prusa MK3 (1.8deg) X/Y/E Stepper Motor | 3 |  | If using a MK3 as source for build: X Motor --> X Axis (Left Side); E Motor --> Z Axis (Right Side); Y Motor --> Y Axis | https://www.prusa3d.com/product/stepper-motor-x-axis-mk3-s-mk2-5-s-mk2-s/
Motors | OPTION C | Prusa MK4 (0.9deg) X/Y Stepper Motor | 3 |  | If using a MK4 as source for build; X Motor --> X Axis (Left Side); Y Motor --> Y Axis; PURCHASE ADDITIONAL MATCHING Prusa X or Y motor for Z Axis (Right Side) | https://www.prusa3d.com/product/stepper-motor-x-axis-3/
Z Rods | OPTION A - 10mm | Linear Rod - 10x325mm | 2 |  | MK4 Spec. If you need to buy rods, the 10mm is the way to go! | https://www.prusa3d.com/product/smooth-rod-325x10-mm/
Z Rods | OPTION A - 10mm | LM10LUU | 2 |  | Matching 10mm bearings for the 10x325mm Z Rod Option | https://www.prusa3d.com/product/linear-bearing-lm10luu/ | https://levendigs.com/products/myt-lm10luu-linear-bearing-1pc
Z Rods | OPTION B - 8mm | Linear Rod - 8x320mm | 2 |  | MK3 Spec. Fine to use if you have them on hand, but if you need to purchase, go 10mm.
Z Rods | OPTION B - 8mm (short bearings) | LM8UU | 4 |  | If using 8mm Z Rods, use either 2x LM8UU per side or 1x LM8LUU per side with the correct printed adapter | https://www.prusa3d.com/product/linear-bearing-lm8uu/ | https://west3d.com/products/lm8uu-smooth-rod-8x15x45-linear-bearing?dt_id=524416 | https://levendigs.com/products/myt-lm8uu-linear-bearing-1pc | https://3do.dk/en/bearings/385-lm8uu.html
Z Rods | OPTION B - 8mm (long bearings) | LM8LUU | 2 |  | If using 8mm Z Rods, use either 2x LM8UU per side or 1x LM8LUU per side with the correct printed adapter | https://kb-3d.com/store/motion/192-lm8luu-linear-bearing-1634423402210.html?affp=22155 | https://west3d.com/products/lm8luu-smooth-rod-8x15x45-linear-bearing?dt_id=524416
Y CARRIAGE AND RELATED PARTS
RECOMMENDED CHOICES:
Heatbed Mounting: Option A - MK4 Spec Expansion Joints and related hardware
Y Carriage: whatever is cheaper, doesn't really matter
Y Bearing Clips: Option A: MK4 Style Bearing Clips
Category | YOU CHOOSE! | Part | Quantity | Optional? | Notes | Source 1 | Source 2 | Source 3 | Source 4
Heatbed Mounting | OPTION A - MK4 Spec | Bushing 3.1x6x8mm | 1 |  | This is the center support when using the Prusa Expansion joints. Prusa doesn't sell this directly, but only as part of the MK4S Spare Parts kit. If you're using a MK3.9/MK4(S) and already have the expansion joints, you probably already have this! | https://www.prusa3d.com/product/spare-parts-mk4s-set/ | https://www.mcmaster.com/92871A011/ | https://www.tme.eu/en/details/dr336_3.2x8/metal-spacers/dremec/336-3-2x08/
Heatbed Mounting | OPTION A - MK4 Spec | M3x14 FHCS | 1
Heatbed Mounting | OPTION A - MK4 Spec | M3x4 FHCS | 8
Heatbed Mounting | OPTION A - MK4 Spec | M3x6 BHCS | 8
Heatbed Mounting | OPTION A - MK4 Spec | Prusa Bed Expansion Joint (set) | 8 |  | If you're using a MK3.9/MK(S) as the base, you may already have this. These perform better than the MK3 spec spacers. | https://www.prusa3d.com/product/expansion-joints-set/
Heatbed Mounting | OPTION B - MK3 Spec | Bed Spacer (~3mm ID x6mm OD x 6mm L) | 9 |  | MK3 Spec. Fine to use if you have on hand. | https://www.prusa3d.com/product/heatbed-spacer/
Heatbed Mounting | OPTION B - MK3 Spec | M3x14 FHCS | 9
Y Bearing Clips | OPTION A | MK4 Style Bearing Clips (set) | 1 |  | Use whatever you have if you're starting with a MK3 or MK4 base. If you are buying new, the bearing clips are highly recommended over the older U bolts (MK3-era). | https://www.prusa3d.com/product/bearing-clips/
Y Bearing Clips | OPTION B | MK3 Style Bearing U Bolts (set) | 1 |  |  | https://www.prusa3d.com/product/u-bolts/
Y-Carriage | OPTION A | Prusa MK3 Y Carriage | 1 |  | If you have either option on hand, use it. Else, buy whatever is cheapest! | https://west3d.com/products/prusa-mk3-y-carrier-trianglelab?dt_id=524416 | https://www.onetwo3d.co.uk/product/ldo-switchwire-y-carriage/
Y-Carriage | OPTION B | Prusa MK4 Y Carriage | 1 |  |  | https://www.prusa3d.com/product/y-carriage/
MISCELLANEOUS
Category | YOU CHOOSE! | Part | Quantity | Optional? | Notes | Source 1 | Source 2 | Source 3 | Source 4
Miscellaneous |  | 2020 T-Slot Aluminum Extrusion x 350mm Length (HFS5-2020-350) | 1 |  | X Axis Gantry; MISUMI Reference Part# HFS5-2020-350 | https://dllpdf.com/dllpdf-2020-by-the-mm | https://hobby-store.pl/en/aluminium-profile-2020-type-t-slot/altrax-aluminium-profile-2020-t-slot-type-matt-black.html | https://us.misumi-ec.com/vona2/detail/110302683830/?HissuCode=HFSB5-2020-350 | https://de.misumi-ec.com/vona2/detail/110302683830/?HissuCode=HFSB5-2020-350
Miscellaneous |  | 2mm or 3mm Nylon - 555mm length | 2 |  | This is the nylon used on Nextruder. It will be used for the Stealthburner wiring. It can also be used on the heated bed if you don't have your old nylon anymore. If that is the case, purchase two of them. You can also source a small length of ~3mm Nylon filament as well! | https://www.prusa3d.com/product/nylon-3x555-mm/
Miscellaneous |  | Door Puller 63mm; 1kg pull force | 1 |  | This is used in place of a branded Key-Bak, as it is more accessible to purchase outside of the USA. Remixes for Switchwire spec (Key-Bak Super48 36in 13oz) exist as well. | https://www.amazon.com/dp/B0F2M9GKDT?th=1 | https://www.amazon.de/dp/B0BRVBHQ1J
Miscellaneous |  | ECAS Bowden Collet 4mm | 3 | yes | Used for the filament guide if using the top spool mount
Miscellaneous |  | HellermannTyton 170-01000 Helagaine Twist-In Cable Sleeve (300-350mm length) | 1 |  | Used to wrap the MK52 bed cables. For MK3, this part is 300mm. MK3.9 and above, this is 350mm. | https://www.prusa3d.com/product/textile-sleeve-35-cm/ | https://www.tme.eu/de/en/details/twist-in-05-pet-bk/conduits/hellermanntyton/170-01000/ | https://www.conrad.com/en/p/hellermanntyton-170-01000-twist-in-05-helagaine-meshwork-hose-black-541298.html
Miscellaneous |  | HellermannTyton 170-01001 5-8mm Helagaine Twist-In Cable Sleeve (520mm) | 1 |  | Prusa sells this for the Nextruder cable sleeving. We use it for the toolhead. You can roll your own umibical solution as long as it is safe, however. | https://www.prusa3d.com/product/textile-sleeve-8x520-mm/ | https://www.tme.eu/de/en/details/twist-in-08-pet-bk/conduits/hellermanntyton/170-01001/
Miscellaneous |  | Rubber Foot - 14x11x9mm | 4 |  | https://kb-3d.com/store/frame-enclosure/283-rubber-machine-foot-14x11x9mm-set-of-4.html?affp=22155 | https://west3d.com/products/14x11x9mm-little-rubber-feet-with-steel-washer?dt_id=524416 | https://www.replimat.eu/4x-rubber-feet-14x11x9mm-for-v0.2-black/rt10118
Miscellaneous |  | Zip Ties (Bag of 50) | 1
FRAME
In most cases, you already have all of this assembled from a donor machine. Components here are included for reference.
Category | YOU CHOOSE! | Part | Quantity | Optional? | Notes | Source 1 | Source 2 | Source 3 | Source 4
Frame |  | Frame Extrusion - Long | 2 |  |  | https://www.prusa3d.com/product/aluminum-extrusion-long/
Frame |  | Frame Extrusion - Short | 2 |  |  | https://www.prusa3d.com/product/aluminum-extrusion-short/
Frame |  | Front Plate | 1 |  |  | https://www.prusa3d.com/product/front-plate/
Frame |  | M5x30 BHCS | 32
Frame |  | Printer Frame Upright | 1 |  | MK3/S/+ has an older version of this frame. The MK4 version is perforated with hexagons at the rear to reduce weight, and is also a little thicker. Both are fine for this build. | https://www.prusa3d.com/product/printer-frame/
Frame |  | Rear Plate | 1 |  |  | https://www.prusa3d.com/product/rear-plate/
TOOLHEAD
Stealthburner is the official configuration. There are experimental mounts for AntHead, etc. SuperPINDA is the officially supported Z Probe, but PZ-Probe has been known to work and Nextruder Nozzle Tap is coming... as well as Amplify load cell probing!
There are too many hot end and toolhead combinations to account for here. If you are brand new to the Voron world, we suggest a stock Stealthburner build (with the stock CW2 extruder) and Revo Voron.
Category | YOU CHOOSE! | Part | Quantity | Optional? | Notes | Source 1 | Source 2 | Source 3 | Source 4
Toolhead | OPTION A | SuperPINDA | 1 |  | Officially supported for Z Probe | https://www.prusa3d.com/product/superpinda/
Toolhead | OPTION B | PZ-Probe | 1 | yes | ADVANCED USERS ONLY -- it is expensive and tricky to use; Some users have had success with PZ-Probe + Revo
Toolhead | OPTION C | BD Pressure | 1 | yes | Experimental Probe Option - Less expensive than Revo PZ but less is known about this probe | https://www.fabreeko.com/collections/recently-added/products/bd-pressure-realtime-pa-adjustment | https://www.pandapi3d.com/product-page/bdpressuree
Toolhead | OPTION D | Nextruder | 1 | yes
Toolhead |  | Voron Stealthburner | 1 |  | We do not breakout the BOM for the Voron Stealthburner, with the exception of suggesting toolhead boards above. You will need extruder motor, hot end, fasteners, hot end and part cooling fans, and optionally LEDs; https://github.com/VoronDesign/Voron-Stealthburner | https://github.com/VoronDesign/Voron-Stealthburner
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

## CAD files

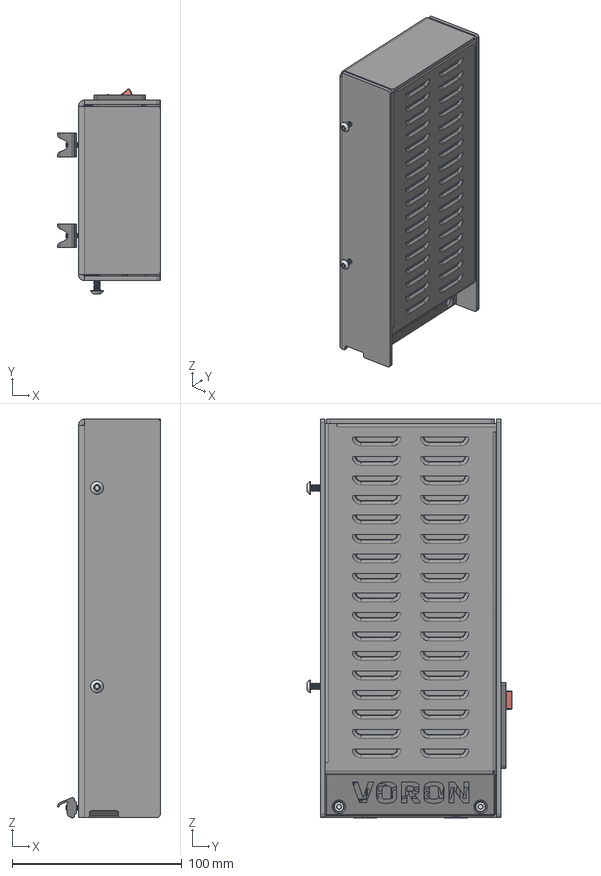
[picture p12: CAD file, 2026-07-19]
CAD/Electronics/PSU Assembly.step
60.7 x 121.2 x 235.3 mm
Switch Housing
Switch
Crimped Spade F
Crimped Spade F (1)
Crimped Spade F (2)
Crimped Spade F (3)
Crimped Spade F (4)
Crimped Spade F (5)
Crimped Spade F (6)
M3x10 SHCS x 4
M4x10 BHCS x 2
DELTA_psu_cover
M3_Hexnut x 2
M3 hex nut T-Nut 3030 x 2
DELTA_psu_cover_1

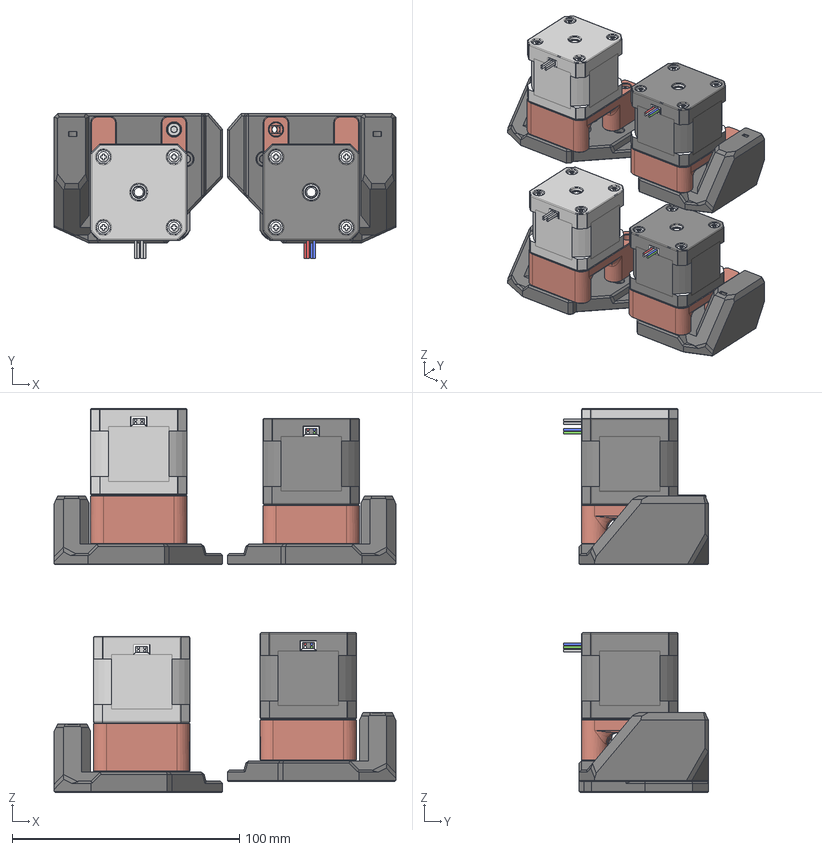
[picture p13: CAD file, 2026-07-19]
CAD/Experimental Files/Double Shear/Standard Motors/Double Shear Assembly.step
150.1 x 63.7 x 168.8 mm
(Unsaved)
M3 Threaded Insert
[a]_motor_mounts_X
X Mount
Grub_screw x 2
Top_Flange
Bottom_Flange
Pulley_Body
M3x20 SHCS x 3
M3x30 SHCS x 2
F695 Bearing
(Unsaved)_1
[a]_motor_mounts_Z
Z Mount
Grub_screw_1 x 2
Top_Flange_1
Bottom_Flange_1
Pulley_Body_1
F695 Bearing_1
(Unsaved)_2
GT2 20T 6MM Pulley
[a]_motor_mounts_Z_1
Z Mount_1
F695 Bearing_2
[a]_motor_mounts_X_1
X Mount_1
(Unsaved)_3
GT2 20T 6MM Pulley_1
F695 Bearing_3

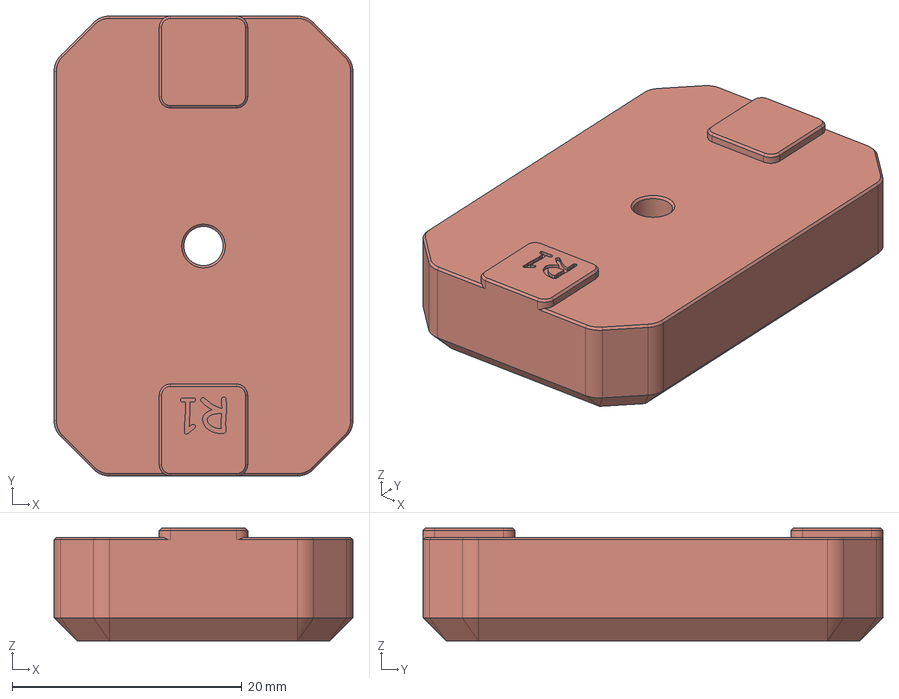
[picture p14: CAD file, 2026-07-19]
CAD/Frame/Feet Assembly.step
26.0 x 40.0 x 9.80 mm

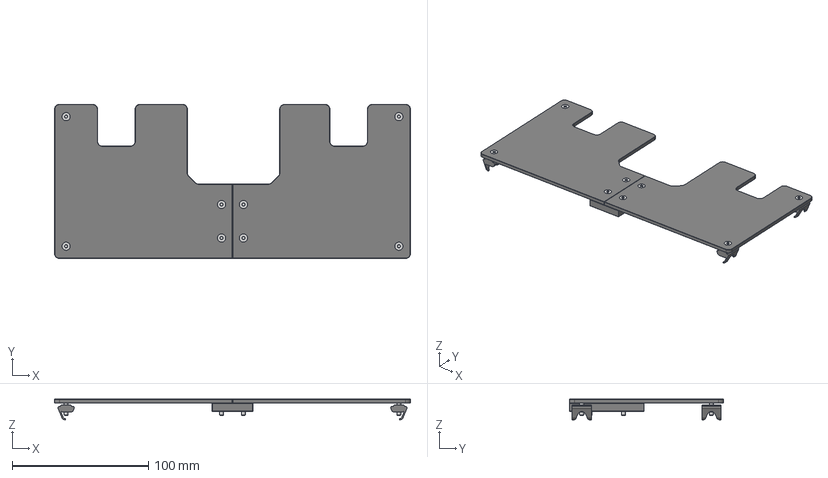
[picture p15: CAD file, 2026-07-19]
CAD/Panels/Rear Panel Assembly.step
261.0 x 113.1 x 15.3 mm
deck_panel_rear_connector
deck_panel_rear_left
M3_Hexnut x 4
M3 hex nut T-Nut 3030 x 4
M3_Hexnut_1 x 4
M3x12 FHCS x 8
deck_panel_rear_right_deltablackpsu

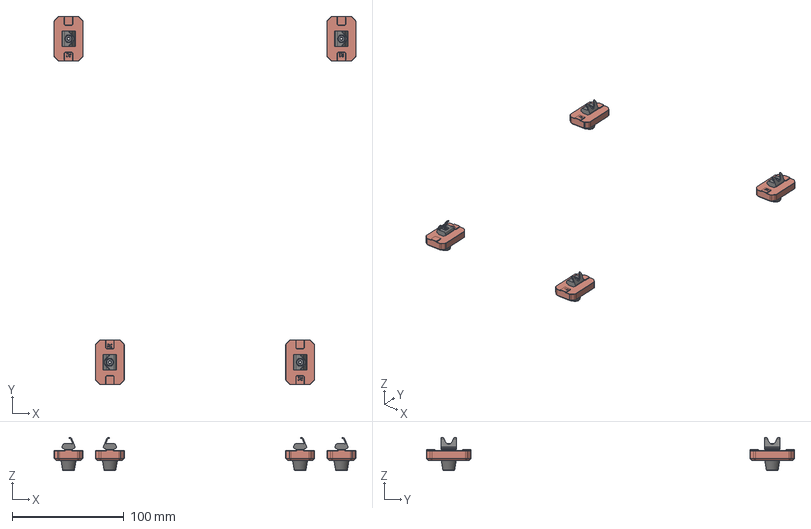
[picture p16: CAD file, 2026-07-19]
CAD/Frame/Feet Assembly (Assembly).step
270.0 x 329.2 x 29.9 mm
M3x20 SHCS x 4
Rubber Foot - 14x11x9mm x 4
[a]_rubber_foot_block_x4 x 4
M3_Hexnut x 4
M3 hex nut T-Nut 3030 x 4

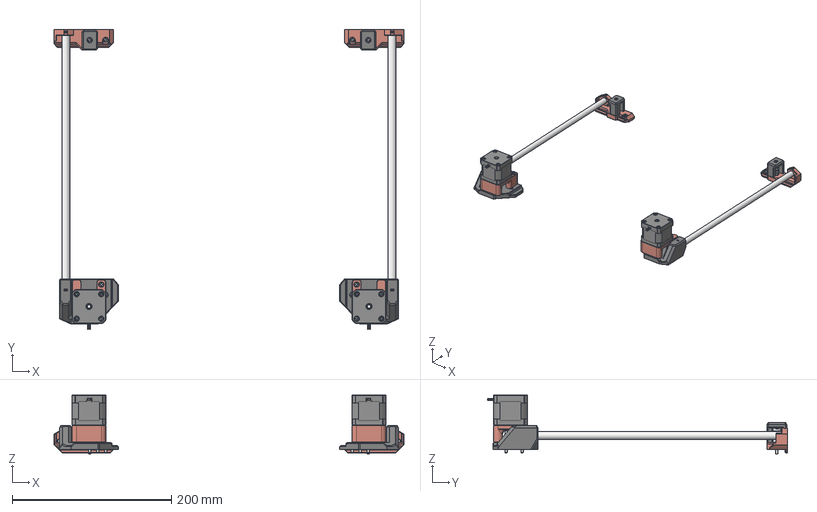
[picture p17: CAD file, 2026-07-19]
CAD/XZ_Axis/XZ Axis Assembly.step
439.6 x 377.2 x 74.1 mm
Linear Rod - 10x325mm x 2
M3 Threaded Insert
z_idler_block_b
Z_Upper_Idlers
M3 Shim 0.5mm x 6mm x 12
F623 Bearing x 8
M3x10 SHCS
M3x30 SHCS_1 x 2
(Unsaved)
Z Mount
Grub_screw x 2
Top_Flange
Bottom_Flange
Pulley_Body
[a]_motor_mounts_Z
M3x10 SHCS_1 x 3
M3x20 SHCS x 3
M3x30 SHCS x 2
M3 Threaded Insert_1
x_idler_block_b
X_Upper_Idlers
M3 Threaded Insert_2
M3x10 SHCS_2
(Unsaved)_1
M3 Threaded Insert_3
[a]_motor_mounts_X
X Mount
Grub_screw_1 x 2
Top_Flange_1
Bottom_Flange_1
Pulley_Body_1
M3x10 SHCS_3 x 3
M3x20 SHCS_1 x 3
M3x30 SHCS_2 x 2

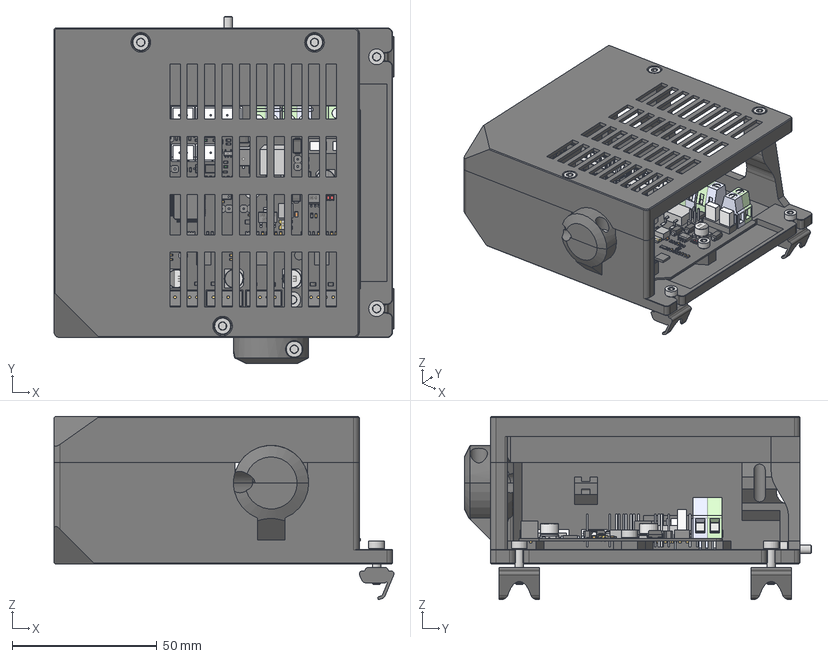
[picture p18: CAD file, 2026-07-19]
CAD/Electronics/SKR Assembly.step
117.5 x 120.0 x 63.3 mm
mcu_cover_skr_mini_e3
Strip
Button
Sheet_Metal_Part6 x 2
Pin
DO214AC-SMA_S1G x 9
R0603 x 90
User_Library-XH2_54_2PIN x 9
User_Library-LED_0603_G_Pocket002 x 6
User_Library-LED_0603_G_Pad004 x 6
User_Library-LED_0603_G_Fillet x 6
User_Library-LED_0603_G_Pocket001 x 6
User_Library-LED_0603_G_Pad x 6
KF128 x 3
Extruded_20 x 54
Extruded_21 x 27
Extruded_23 x 44
Extruded_24 x 22
Extruded_12 x 5
Extruded_13 x 5
Extruded_19 x 8
Extruded_15 x 8
Extruded_14 x 5
LOGO?
USB_micro_A_1
Extruded x 4
Extruded_16 x 3
Extruded_17 x 3
Extruded_18 x 3
Extruded_1
User_Library-led_0805 x 2
TQFP-64_10x10
TSSOP-8
SO-8
Extruded_2
Extruded_3
Extruded_4
Extruded_5
Extruded_6
User_Library-0805_SMD_Capacitor x 4
Extruded_8 x 2
Extruded_7
SL-E x 5
R0805 x 9
TO-252
User_Library-R-0603-Array-4-1 x 4
SOT-223_MP04A
User_Library-GeyerElectronics_KX7
Extruded_9
Extruded_10
Extruded_11
TO263
TSSOP14-1
SOT-23-5 x 2
User_Library-R1812-PTC
Extruded_22
mcu_base_skr_mini_e3
M3 Threaded Insert x 10
heatbed_cable_clip
M3x10 SHCS x 2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

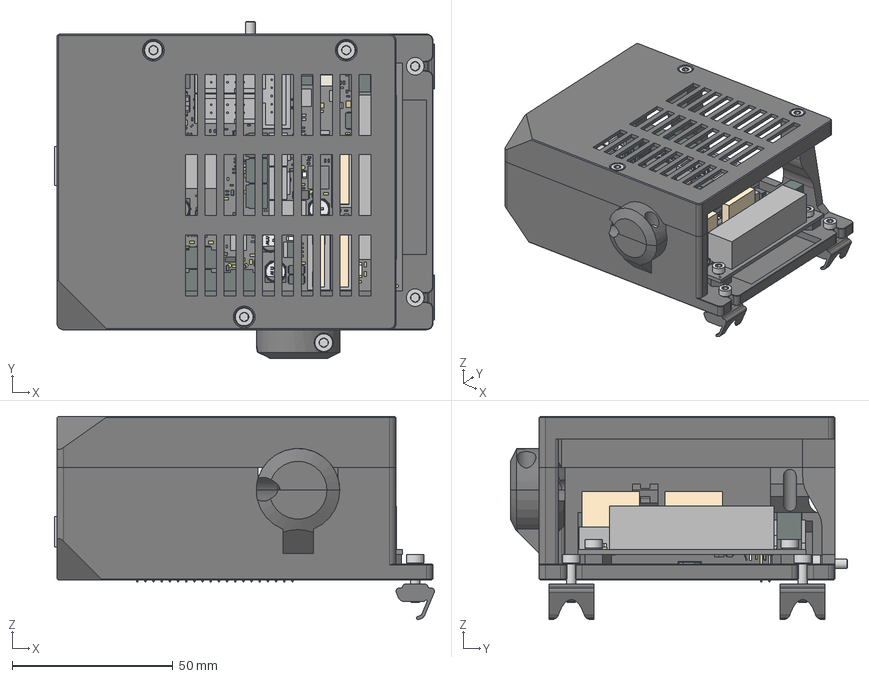
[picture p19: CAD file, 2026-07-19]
CAD/Electronics/Rambo Assembly.step
118.2 x 105.0 x 63.3 mm
PCB
mcu_base_einsy
mcu_cover_einsy
M3 Threaded Insert x 9
M3x10 SHCS x 2
heatbed_cable_clip
M3x20 SHCS x 3
M3x8 SHCS x 5
M3x12 SHCS x 2
M3 hex nut T-Nut 3030 x 2
M3_Hexnut x 2
Board
shield x 2
socket_housing x 2
socket_plate x 2
terminal x 10
HDRV40W64P254_2X20_5080X508X838B
CAPC-0402-T0.55-BN x 49
CAPC-0603-T0.9-BN x 2
INDC-0603 x 2
INDC-0402 x 6
CAPC-0805-T0.95-BN x 7
CAPC-1206-T1.4-BN
RESC-0402 x 14
SRN4018
Micro SD slot
Housing
Shielding
Housing2
Pin1 x 18
Pin2

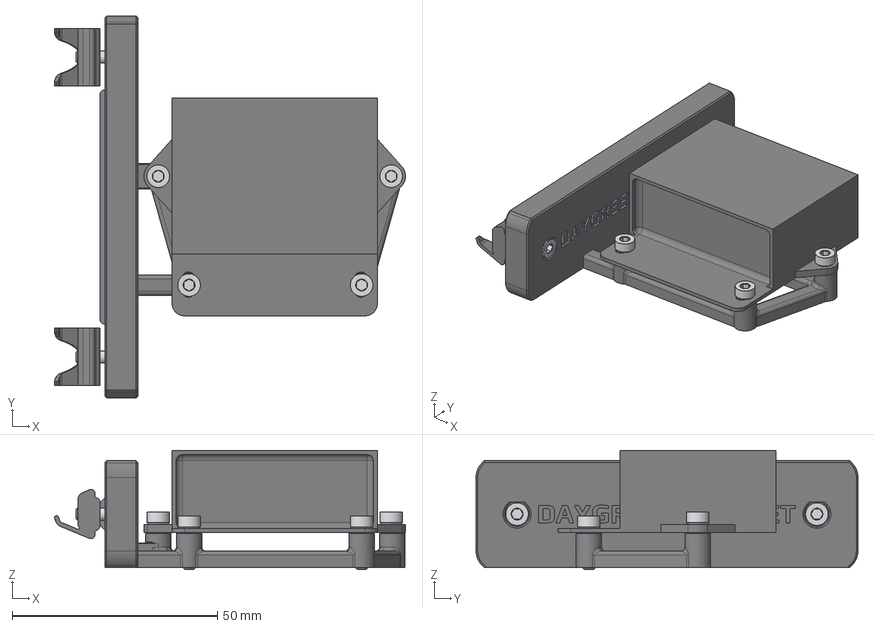
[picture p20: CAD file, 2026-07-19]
CAD/Electronics/Buck Converter Assembly.step
85.5 x 93.0 x 29.0 mm
Daygreen 24V to 5V Converter
daygreen_mosfet_bracket
M3 hex nut T-Nut 3030 x 2
M3_Hexnut x 2
M3x12 SHCS x 2
M3x10 SHCS x 4

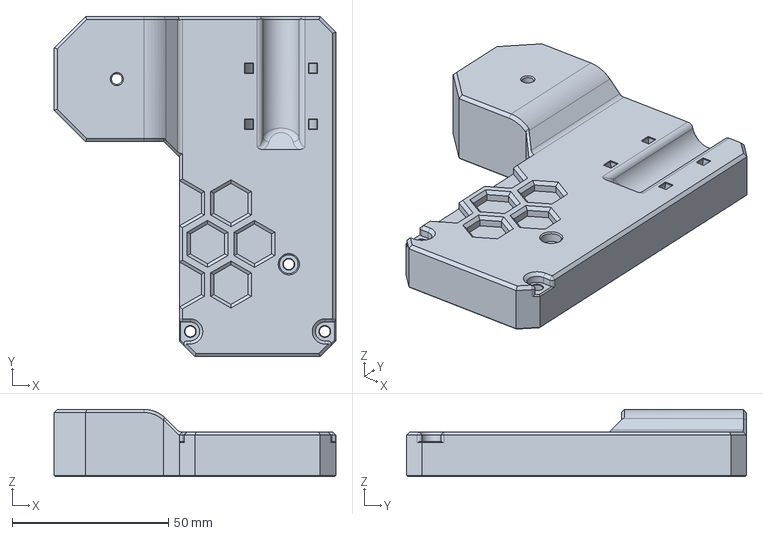
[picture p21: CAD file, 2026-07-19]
CAD/Door_Puller/door_puller_idler_bracket.step
90.0 x 108.7 x 21.5 mm

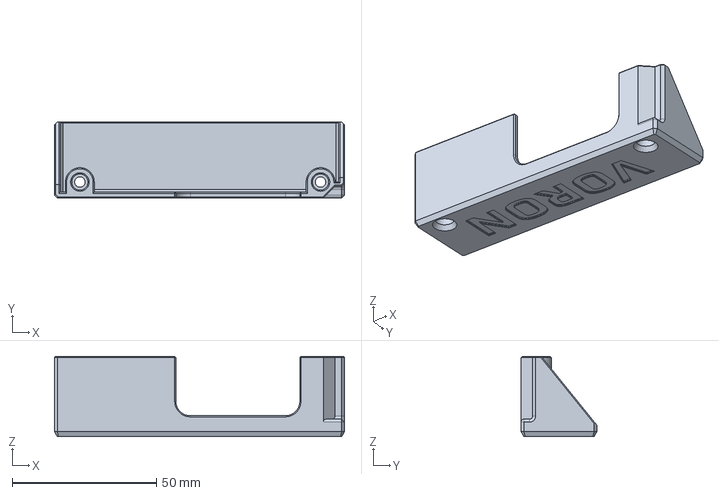
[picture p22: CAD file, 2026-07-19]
CAD/Electronics/Black PSU Covers/black_psu_cover_voron.step
100.6 x 26.3 x 27.9 mm

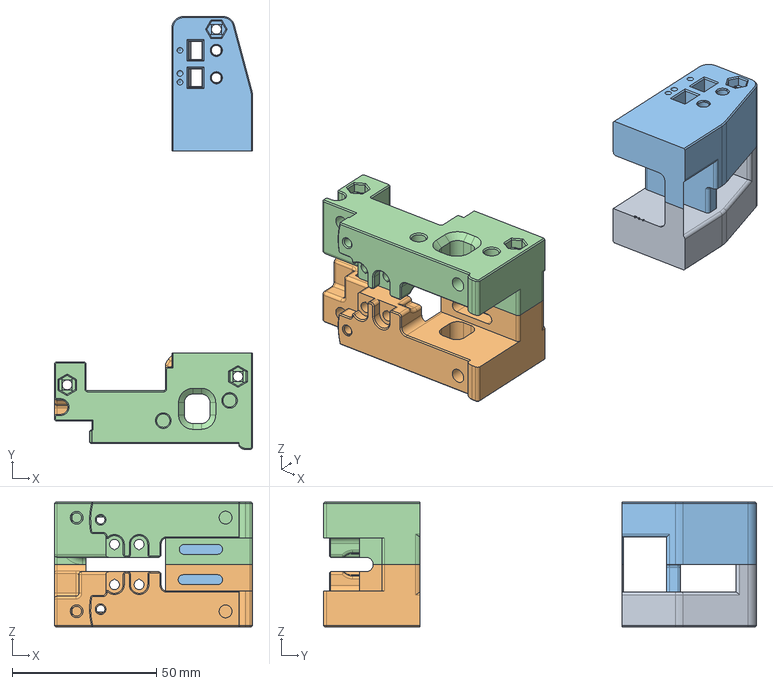
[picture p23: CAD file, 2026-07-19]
CAD/Experimental Files/Belt Attachement Points.step
68.8 x 150.0 x 43.2 mm
x_carriage_left v9
x_carriage_right v12

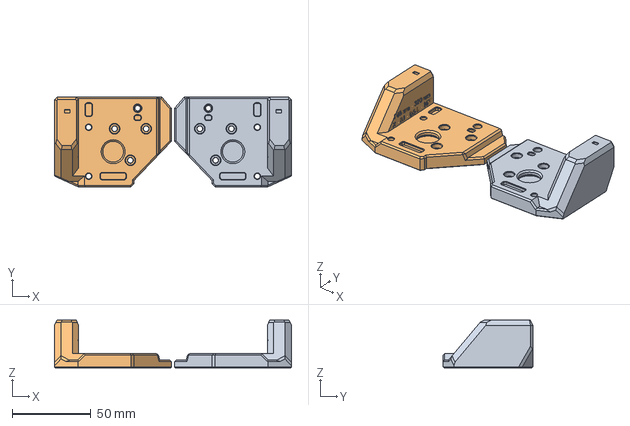
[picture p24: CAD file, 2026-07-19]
CAD/Experimental Files/Double Shear/Long Motor Shafts/STDx8mmx320mmx16T.step
150.1 x 56.8 x 30.1 mm
Z Mount
X Mount (1)

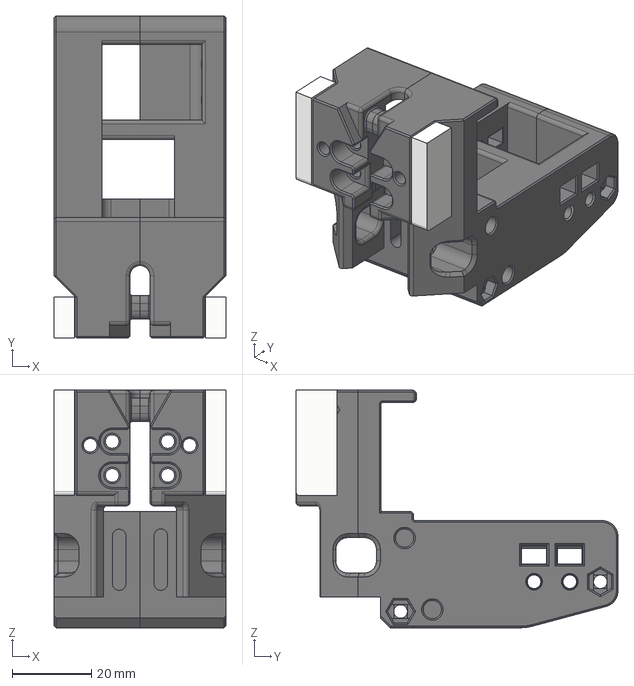
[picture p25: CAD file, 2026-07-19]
CAD/Experimental Files/Expermental Toolheads/x_carriage_db_anthead.step
43.2 x 81.1 x 59.8 mm

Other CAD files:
CAD/Experimental Files/Prusa Bear Files/Frame and Partial Assembly/Bear Frame.step
CAD/Experimental Files/Prusa Bear Files/Keyback Parts/door_puller_idler_bracket_bear.step
CAD/Experimental Files/Prusa Bear Files/XZ Bear Parts/[a]_idler_block_a_bear.step
CAD/Experimental Files/Rear Panel Files/deck_panel_rear_left_20T.step
CAD/Door_Puller/Door Puller Anchor.step
CAD/Door_Puller/Door Puller Idler.step
CAD/Door_Puller/Door Puller.step
CAD/Door_Puller/door_puller_anchor.step
CAD/Door_Puller/door_puller_bracket.step
CAD/Electronics/BTT SB2209 USB Adapter.step
CAD/Electronics/Black PSU Covers/black_psu_cover_prusawire.step
CAD/Electronics/Nitehawk-SB USB.step
CAD/Electronics/Raspberry Pi.step
CAD/Electronics/Wago Mount.step
CAD/Electronics/btt_sb2209_usb_bracket.step
CAD/Electronics/daygreen_mosfet_bracket.step
CAD/Electronics/heatbed_cable_clip.step
CAD/Electronics/mcu_box_einsy.step
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

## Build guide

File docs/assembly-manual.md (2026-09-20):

---
layout: default
title: "Assembly Manual"
nav_order: 5
---

# Assembly Manual

The latest [Prusawire 2026.R1 Assembly Manual can be found on GitHub](https://github.com/Positron3D/Prusawire/blob/main/Manuals/Prusawire_2026.R1_Assembly_Manual.pdf).

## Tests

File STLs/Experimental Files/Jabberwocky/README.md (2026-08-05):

# Jabberwocky Mount

This is an experimental x-carriage/mount for Jabberwocky on the Prusawire 2026.R1.  

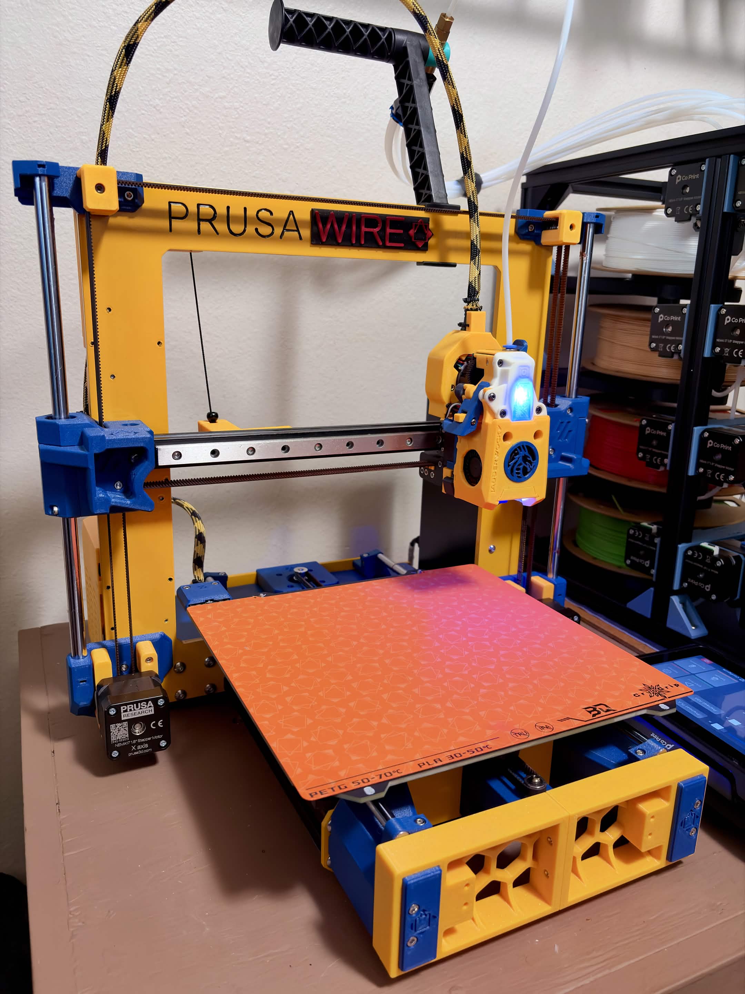
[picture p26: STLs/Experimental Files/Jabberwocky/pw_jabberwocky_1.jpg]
Jabberwocky toolhead mounted on a Prusawire 2026.R1
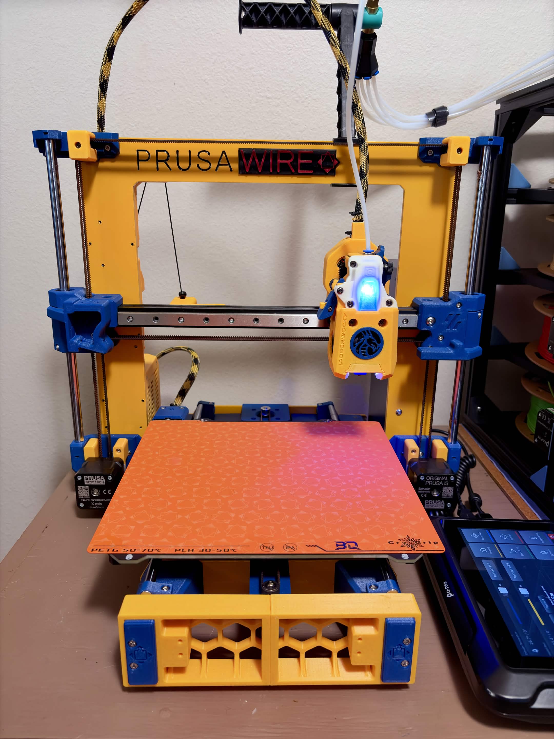
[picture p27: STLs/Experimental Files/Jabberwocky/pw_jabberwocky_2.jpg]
Front view of the Jabberwocky toolhead on a Prusawire 2026.R1
 

Use these files in lieu of the stock stealthburner mount files.  You may source the rest of Jabberwocky from the [Github](https://github.com/kinematicdigit/Jabberwocky).

If you use this, please give us feedback on either Discord or in GitHub issues! We are happy to help revise the mount as needed.

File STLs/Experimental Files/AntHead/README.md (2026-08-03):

# AntHead Mount

This is an experimental x-carriage/mount for AntHead on the Prusawire 2026.R1.  Use these files in lieu of the stock left and right x-carriage files.  You may source the rest of AntHead from the [PrintersForAnts Github](https://github.com/PrintersForAnts/AntHead).

If you use this, please give us feedback on either Discord or in GitHub issues! We are happy to help revise the mount as needed.

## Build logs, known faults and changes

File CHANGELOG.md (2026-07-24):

# Prusawire Change Log

Updated periodically to note significant design changes, fixes, and enhancements.

- 2026-07-24
    - Official Release of 2026.R1!
        - [Article: Prusawire R1 - Designed With Leftovers](https://www.printables.com/article/prusawire-r1-designed-with-leftovers-VNGb2GZ).
        - Complete revamp of Y Axis (belt path, tensioning, accounting for MK3 and MK4 Y Carriages)
        - Re-engineering of XZ Belt Paths to improve overall performance.
        - CAD cleanup, general small polish throughout the project.
- 2025-11-15
    - Update y_belt_tensioner_front to allow recessed screw cap head.  Update tensioner screw to M3x16 SHCS in BOM.  Update y_belt_tensioner_rear to have M3S and V0SN variants. (via @erikbuild)
- 2025-11-05
    - Documentation site launched ([https://prusawire.positron3d.com](https://prusawire.positron3d.com)) (via @erikbuild)
- 2025-10-31
    - Update XZ Blocks to have a variant for Prusa-style slim M3 Square Nuts as well as V0-style M3 Square Nuts. (via @Safe-ty)
    - Update Upper Idler Blocks to increase tolerance band for Z-rod lengths. (via @Safe-ty)
- 2025-10-11
    - y_idler_bracket replaced / updated with much stronger version. (via @erikbuild)
    - Added Rod Length Compatibility to motor mounts and idler brackets (via @Safe-ty)
        - Support 8mm rods: 320, 325, and 330mm lengths
        - Support 10mm rods: 320, 325, 330, and 341 lengths
        - Changed file structure to sort motor mounts by diameter
- 2025-10-07
    - Support for V0 Square Nuts for XZ Blocks, Y-Axis Parts (via @Safe-ty)
- 2025-10-06
    - Increase tolerance for 2020 Extrusion Length in XZ Blocks (via @Safe-ty)
        - Allow for 350 +2.0mm length
- 2025-08-26
    - Update idler blocks to eliminate belt rubbing (via @Ellafoxo)
- 2025-08-21
    - 2025.B1 "Beta 1" Released! (via @Ellafoxo)

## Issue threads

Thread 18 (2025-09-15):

Decrease Probe Temperature

TheNexusAvenger, 2025-09-15:
During my testing with the default profile using the E3D PZ probe, I had issues with melting plastic making dots over the probe positions and causing really bad bed mesh results. For my prints (only with PLA), I swapped the following from the Start G-code:
```
SET_HEATER_TEMPERATURE HEATER=extruder TARGET=[first_layer_temperature[initial_tool]]
SET_HEATER_TEMPERATURE HEATER=heater_bed TARGET=[first_layer_bed_temperature] MINIMUM={first_layer_bed_temperature[0]-2}

TEMPERATURE_WAIT SENSOR=heater_bed MINIMUM={first_layer_bed_temperature[0]-2}
TEMPERATURE_WAIT SENSOR=extruder MINIMUM=[first_layer_temperature[initial_tool]]

BED_MESH_CALIBRATE
```

To:
```
SET_HEATER_TEMPERATURE HEATER=extruder TARGET=150
SET_HEATER_TEMPERATURE HEATER=heater_bed TARGET=[first_layer_bed_temperature] MINIMUM={first_layer_bed_temperature[0]-2}

TEMPERATURE_WAIT SENSOR=heater_bed MINIMUM={first_layer_bed_temperature[0]-2}
TEMPERATURE_WAIT SENSOR=extruder MINIMUM=150

BED_MESH_CALIBRATE

SET_HEATER_TEMPERATURE HEATER=extruder TARGET=[first_layer_temperature[initial_tool]]

TEMPERATURE_WAIT SENSOR=extruder MINIMUM=[first_layer_temperature[initial_tool]]
```

This change reduces the nozzle temperature to 150c during probing and then raises it up to the intended temperature before printing. This is based on Prusa doing the same, except at 170c instead. I haven't opened a pull request for this since I'm not sure if these changes make sense (either the concept as a default, or the implementation), but I can create a pull request with some feedback.

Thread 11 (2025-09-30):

MK3 Original Frame Issues

nomadsgalaxy, 2025-09-30:
From LordWalls on [discord](https://discord.com/channels/994721150804443266/1377366877571121182/1422687237782376481);
> 1. Y carriage when near Y Max touches the front panel that secures the lcd
> 2. The m3x40 that hold the X and Y  bearing stack on top of the frame pass throw to the other side, hitting the door cable bearing thing

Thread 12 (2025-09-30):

Y-axis Re-design

Safe-ty, 2025-09-30:
The stock y-axis design is rather floppy. issue opened to investigate alternate designs

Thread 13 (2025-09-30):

Rail Printed part

Safe-ty, 2025-09-30:
Printed part included on printables is not symmetric - part has been redesigned and is pending implementation.

Safe-ty, 2025-10-07:
Cad Fixed

Closed 2025-10-07.

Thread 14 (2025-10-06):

X-axis aluminium profile length / XZ-block stopper position

KalleFornication, 2025-10-06:
The two faces (marked in orange) at the XZ-stopper blocks have a distance of 350 mm while the target length of the 20x20 aluminium profile is also 350 mm. In reality, when ordering a profile at this length, it will likely exceed the target length by about to 1 mm, so there is some clearance necessary between the two touching faces on the XZ-stoppers. No clearance in combination with a too long aluminium profile will push the XZ-blocks outwards and lead to pressure on the bearings and deformation of the linear rods. Since the stop-faces (orange) are not necessary for the stiffness of the assembly, I suggest to either move the two faces outwards by at least 0.5 mm each or change the target length of the aluminium profile to 349 mm.
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

Safe-ty, 2025-10-06:
@KalleFornication great catch. I will try and update the design files to allow an extrusion tolerance of either =-1mm or =-0.5mm on overall length.

Safe-ty, 2025-10-07:
Design changed to accommodate 350 +2mm overall length for extrusion.

Closed 2025-10-07.

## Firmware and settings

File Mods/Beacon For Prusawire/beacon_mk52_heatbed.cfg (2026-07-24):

[beacon]
serial: /dev/serial/by-id/usb-Beacon_Beacon_RevH_<..addyourserial..>-if00
x_offset: 0 # update with offset from nozzle on your machine
y_offset: 14.6 # update with offset from nozzle on your machine
mesh_main_direction: x
mesh_runs: 2
home_gcode_pre_x: _HOME_PRE_AXIS AXIS=X
home_gcode_post_x: _HOME_POST_AXIS AXIS=X
home_gcode_pre_y: _HOME_PRE_AXIS AXIS=Y
home_gcode_post_y: _HOME_POST_AXIS AXIS=Y
home_xy_position: 66, 30 # update with your safe spot without bed magnets
home_z_hop: 3
home_z_hop_speed: 30
home_xy_move_speed: 150
home_method: contact # use proximity for induction homing
home_method_when_homed: proximity # after initial calibration use induction
home_autocalibrate: unhomed # contact will calibrate beacon on first home
contact_max_hotend_temperature: 170

[bed_mesh]
speed: 150
#horizontal_move_z: 16.55
mesh_min: 25,25
mesh_max: 225,170
probe_count: 50,50
algorithm: bicubic
fade_start: 1
fade_end: 10
fade_target: 0
faulty_region_1_min: 118, 0
faulty_region_1_max: 148, 24
faulty_region_2_min: 182, 0
faulty_region_2_max: 246, 30
faulty_region_3_min: 102, 35
faulty_region_3_max: 139, 77
faulty_region_4_min: 205, 55
faulty_region_4_max: 246, 70
faulty_region_5_min: -4, 80
faulty_region_5_max: 97, 123
faulty_region_6_min: 149, 87
faulty_region_6_max: 246, 125
faulty_region_7_min: 101, 127
faulty_region_7_max: 143, 172
faulty_region_8_min: 92, 181
faulty_region_8_max: 126, 232
faulty_region_9_min: 171, 176
faulty_region_9_max: 210, 232

[gcode_macro _HOME_PRE_AXIS]
gcode:
  # Adapt this for your printer.
  {% set RUN_CURRENT_X = printer.configfile.settings['tmc2209 stepper_x'].run_current|float %}
    {% set RUN_CURRENT_Z = printer.configfile.settings['tmc2209 stepper_z'].run_current|float %}
    {% set RUN_CURRENT_Y = printer.configfile.settings['tmc2209 stepper_y'].run_current|float %}
    {% set HOME_CURRENT_X = RUN_CURRENT_X / 2 %}
    {% set HOME_CURRENT_Z = RUN_CURRENT_Z / 2 %}
    {% set HOME_CURRENT_Y = RUN_CURRENT_Y / 2 %}

    SET_TMC_CURRENT STEPPER=stepper_x CURRENT={HOME_CURRENT_X}
    SET_TMC_CURRENT STEPPER=stepper_z CURRENT={HOME_CURRENT_Z}
    SET_TMC_CURRENT STEPPER=stepper_y CURRENT={HOME_CURRENT_Y}

[gcode_macro _HOME_POST_AXIS]
gcode:
  {% set axis = params.AXIS %}
  {% set RUN_CURRENT_X = printer.configfile.settings['tmc2209 stepper_x'].run_current|float %}
  {% set RUN_CURRENT_Z = printer.configfile.settings['tmc2209 stepper_z'].run_current|float %}
  {% set RUN_CURRENT_Y = printer.configfile.settings['tmc2209 stepper_y'].run_current|float %}

  # Move away
  SAVE_GCODE_STATE NAME=home_post_axis
  G91
  G0 {axis} 10 F3600
  RESTORE_GCODE_STATE NAME=home_post_axis

  # Make sure StallGuard registers are cleared
  M400
  # Set current during print
  SET_TMC_CURRENT STEPPER=stepper_x CURRENT={RUN_CURRENT_X}
  SET_TMC_CURRENT STEPPER=stepper_z CURRENT={RUN_CURRENT_Z}
  SET_TMC_CURRENT STEPPER=stepper_y CURRENT={RUN_CURRENT_Y}

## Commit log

2025-09-04 Update README.md
    Updated README to add link to Klipper Config page
2026-07-19 Preparing for the Official Release of 2026.R1!
    [Prusawire BOM - 2026.R1_v20260719.xlsx]
2026-07-19 Author: Safe Date: Mon Jul 13 19:50:39 2026 -0500
    Final Cad?
    Is this the end of the start?
    commit 56f3db93c35cbdb0a974bc471080ca58079dd764
    Author: Safe
    Date: Mon Jul 13 19:50:01 2026 -0500
    Dont forget the Feet
    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
    [8mm_bearing_adapter_x2_LM8LUU.step, 8mm_bearing_adapter_x2_LM8LUU.stl, 8mm_bearing_adapter_x2_LM8UU.step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]
2026-07-19 Update the manual for Trident style motor pulley alignment tools.
2026-07-22 Add printables sync.
2026-07-24 2026.R1 👀
2026-07-24 Create beacon_mk52_heatbed.cfg
    Add Beacon Mod, removing from default klipper configs
    [beacon_mk52_heatbed.cfg]
2026-07-26 Fix XZ Joint Orientation
    Thanks to Fluffea for pointing this issue out. Orientation fixed for STLs.
    [[a]_xz_blocks_M3Sx16T.stl, [a]_xz_blocks_M3Sx20T.stl, [a]_xz_blocks_V0Sx16T.stl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]
2026-07-28 Update manual to note linear rail lubrication and procedure.
2026-07-28 Fix link to Assembly Manual on documentation website.
2026-08-03 Organize AntHead files and create basic README.md for it.
    [x_carriage_db_anthead_left.stl, x_carriage_db_anthead_right.stl]
2026-08-04 Fix titlecase for AntHead.
    [x_carriage_db_anthead_left.stl, x_carriage_db_anthead_right.stl]
2026-08-05 Add Jabberwocky experimental toolhead mount files.
    [JW_Belt_mounts.stl, JW_carriage_mounts_presupported.stl, JW_front_mount_plate.stl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]
2026-08-06 Update PZ Probe Mount for R1 (#82)
    * Add PZ Probe Mount to Mods
    * Add x_carriage_pz_probe files
    * Update PZ Mount to R1
    * Merge split files into one
    * Create README.md
    ---------
    [x_carriage_left_pzprobe.stl, x_carriage_pz_probe.step, x_carriage_pz_probe.stl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]
2026-08-15 Update Tolerances on Front XZ Joint for M5x8 BHCS
    Make front counterbore about 2mm deeper to ensure proper fitment for M5x8 BHSC when screwing into roll in nuts
    [[a]_xz_blocks_M3Sx16T.stl, [a]_xz_blocks_M3Sx20T.stl, [a]_xz_blocks_V0Sx16T.step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]
2026-08-20 docs: Added Y Belt installation and tensioning procedure.
2026-08-20 Correct typo in belt procedure.
2026-08-26 Match Prusa MK4S temperatures. Disable skirt by default.
2026-08-27 Add modified printer_model condition for combined profiles.
2026-09-27 Clarify compatibility of belts
    fixes #81
2026-09-28 Update README with details on existing belts
    Clarified reusability of existing belts in upgrade notes.
2026-09-28 Update README for existing belts reusability
    Clarified wording regarding reusability of existing belts.
